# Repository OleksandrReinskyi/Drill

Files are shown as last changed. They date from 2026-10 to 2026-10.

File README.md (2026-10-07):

# Mini wiertarka

## 1. Opis zasady działania
> Autorzy: Oleksandr Reinskyi 262564, Bohdan Pospolita 262562

**Cel:** Podczas domowej produkcji płytek powstała potrzeba wiercenia otworów w tekstolicie. Dlatego powstał pomysł zaprojektowania wiertarki wlaśnie do tych potrzeb. 

System składa się z trzech modułów:
1. **Zasilacza:** Zasilacz od laptopa 20V/4.5A
2. **Płytka modulacji szerokości impulsów:** Uklad służący do regulowania napięcia na silniku.
3. **Silnik:** Szczotkowy silnik RS385-17V

---

### Zasada działania płytki:

1. Pierwszy wzmacniacz w układzie scalonym LM358 pełni rolę komparatora z histerezą (zrealizowaną za pomocą dzielnika napięcia oraz rezystora w pętli dodatniego sprzężenia zwrotnego), generując napięcie piłokształtne na kondensatorze.

2. Drugi wzmacniacz w układzie LM358 działa jako komparator, porównując napięcie na kondensatorze z napięciem zadanym na potencjometrze. Na wyjściu powstaje przebieg prostokątny o regulowanej szerokości impulsów, który steruje tranzystorem MOSFET załączającym i wyłączającym silnik. Tranzystor jest chroniony przed przepięciami za pomocą szybkiej diody impulsowej.

---

## 2. Realizacja

### Wyniki symulacji (KiCAD)

1. **Przebieg napięcia na bramce tranzystora, gdy wartości rezystorów potencjometra były następujące: 3k/7k (górny/dolny):**

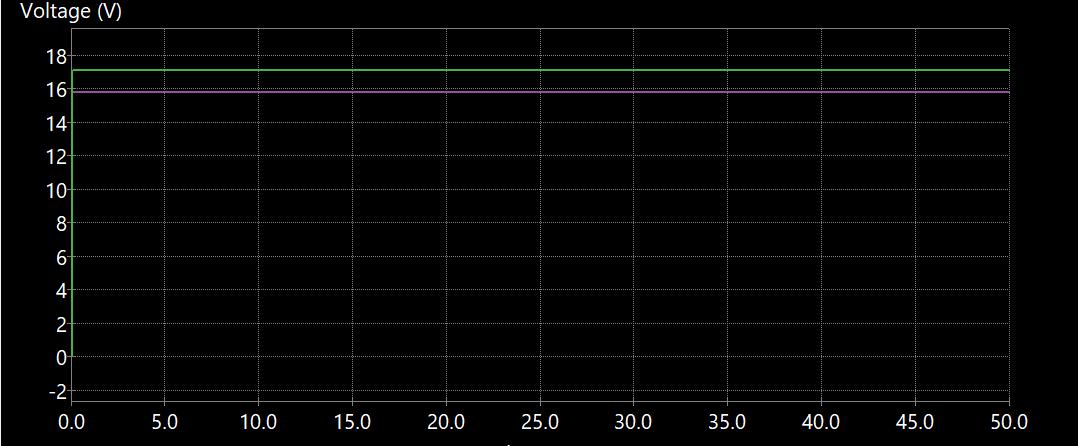
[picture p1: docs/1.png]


2. **Przebieg napięcia na bramce tranzystora, gdy wartości rezystorów potencjometra były następujące: 3k/7k (górny/dolny):**

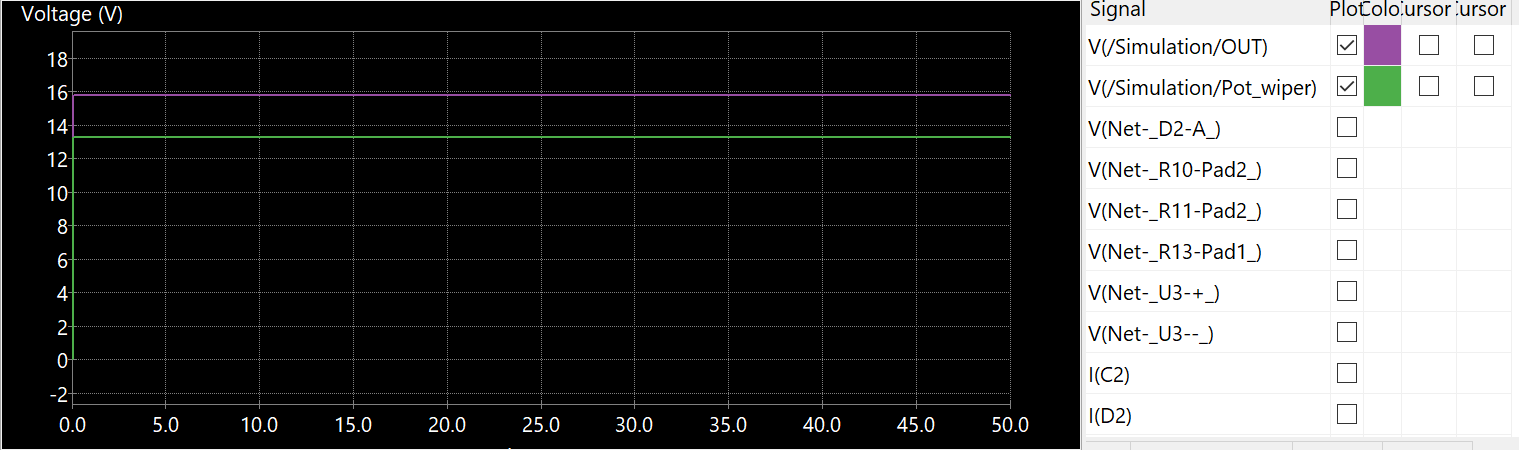
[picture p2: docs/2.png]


### Obudowa
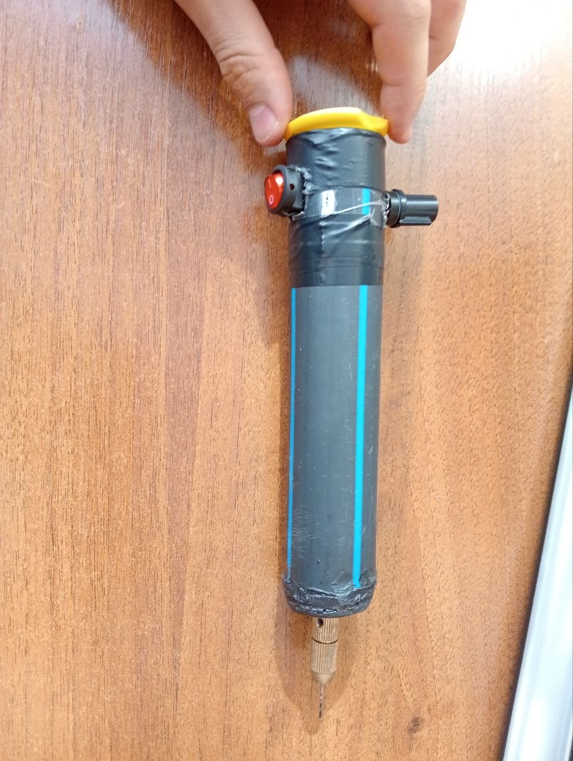
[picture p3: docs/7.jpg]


### Demonstracja wideo
[Link](https://www.youtube.com/shorts/_mu2Nx89iDE)

### Zmontowany prototyp
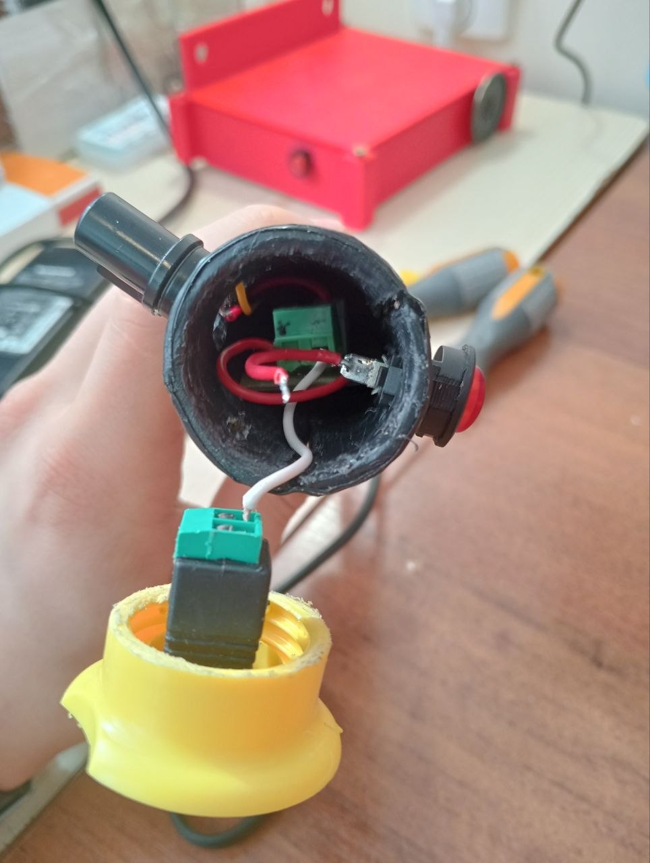
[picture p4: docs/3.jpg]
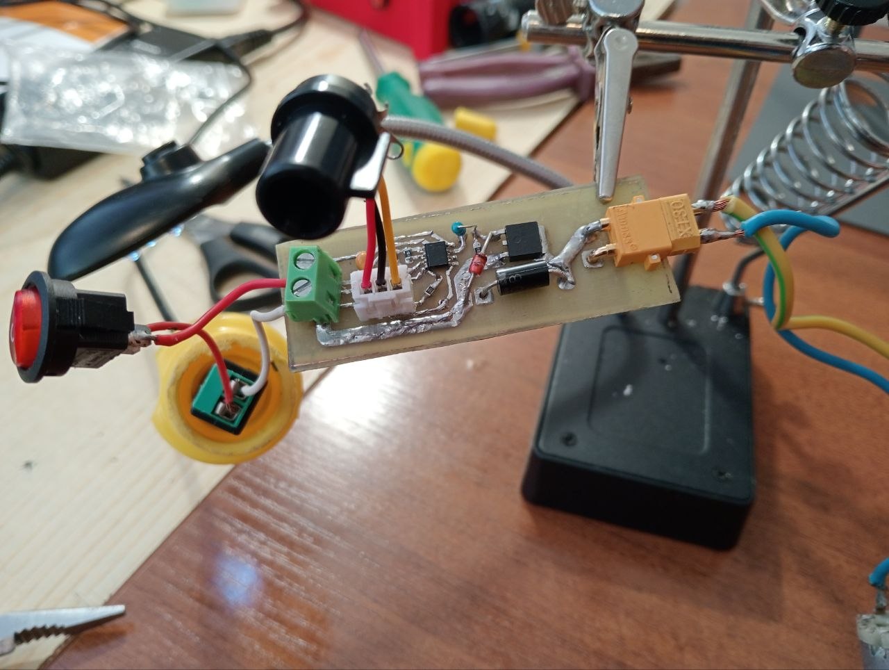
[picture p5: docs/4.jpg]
|  |  |
|--|--|
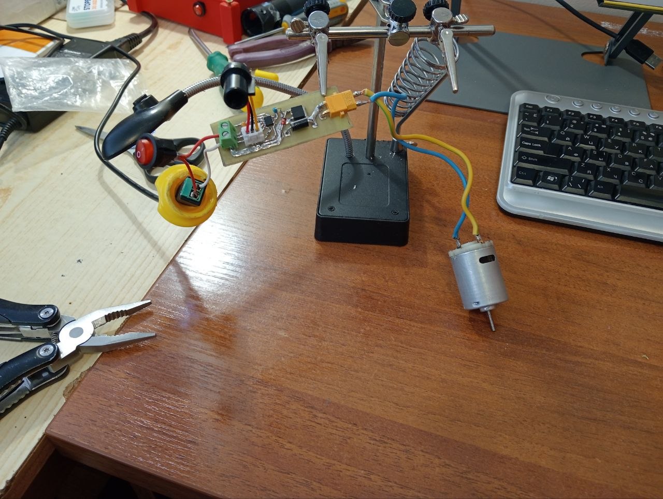
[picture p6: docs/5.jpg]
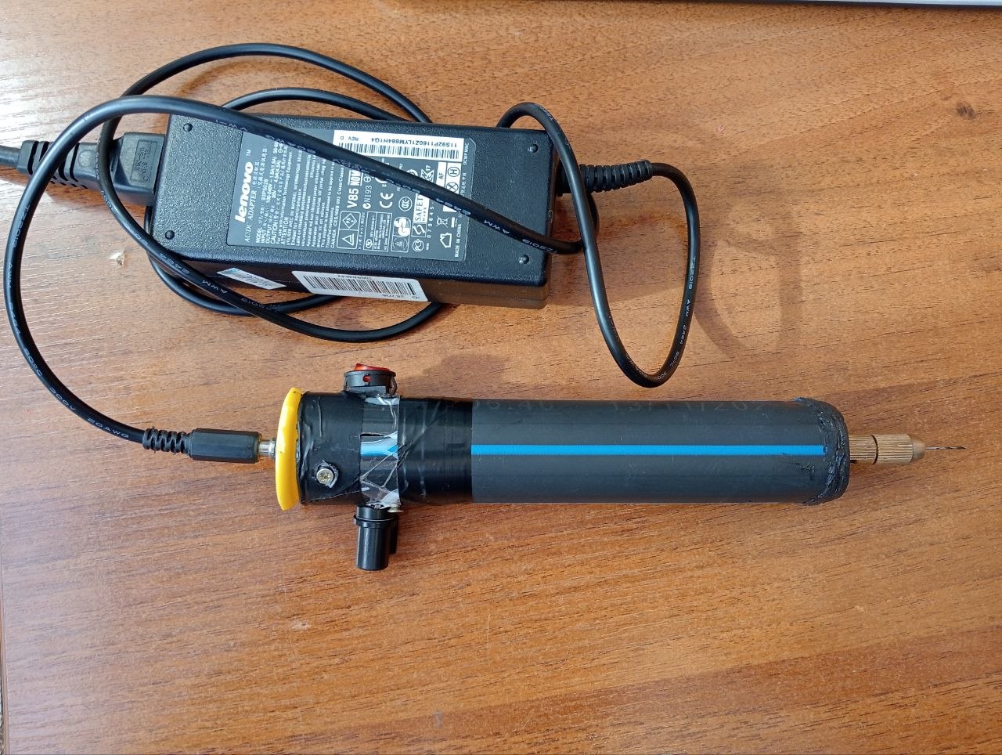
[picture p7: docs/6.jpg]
|  |  |

## 3. Problemy i napotkane trudności 

### Zidentyfikowane problemy:
* Zły dobór wartości rezystorów dzielnika napięcia oraz rezytora sprężenia zwrotnego spowodował, że w sterowaniu napięciem bierze udział nie cała ścieżka potencjometra, a tylko część. Rozwiązać ten problem można dobierając te wartości tak, żeby kondesator ładował się do ~20V oraz rozładowywał się do ~0V.

### Napotkane trudności:
#### 1. Symulacja 
* Najpierw podłączyliśmy wejście drugiego wzmaczniacza do wyjście pierwszego, a nie do węzła kondesatora, i dlatego regulacja była niemożliwa.

#### 2. Dóbór wartości
* Najpierw chcieliśmy zastosować zasiłacz o wartości napięcia 12V, ale wartość maksymalnego prądu silnika (stall current = 5A) przekraczała możliwości zasiłacza. Dlatego wybraliśmy zasiłacz na 20V. Nie zauważyliśmy, że dla wybranego tranzystora LR3103 wartość napięcia między Gate a Source może wynosić maksymalnie 16v. Dlatego musieliśmy dolutować diodę Zenera, która stabilizuje napięcie na poziomie 10v.  

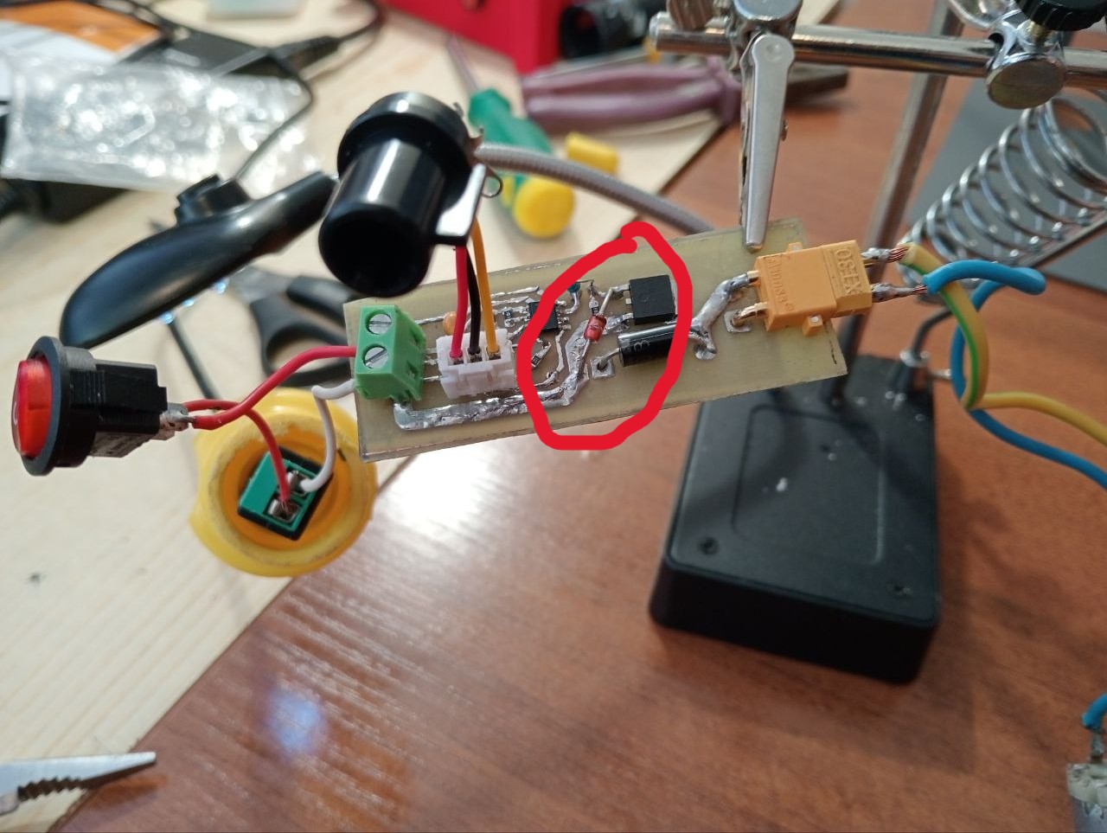
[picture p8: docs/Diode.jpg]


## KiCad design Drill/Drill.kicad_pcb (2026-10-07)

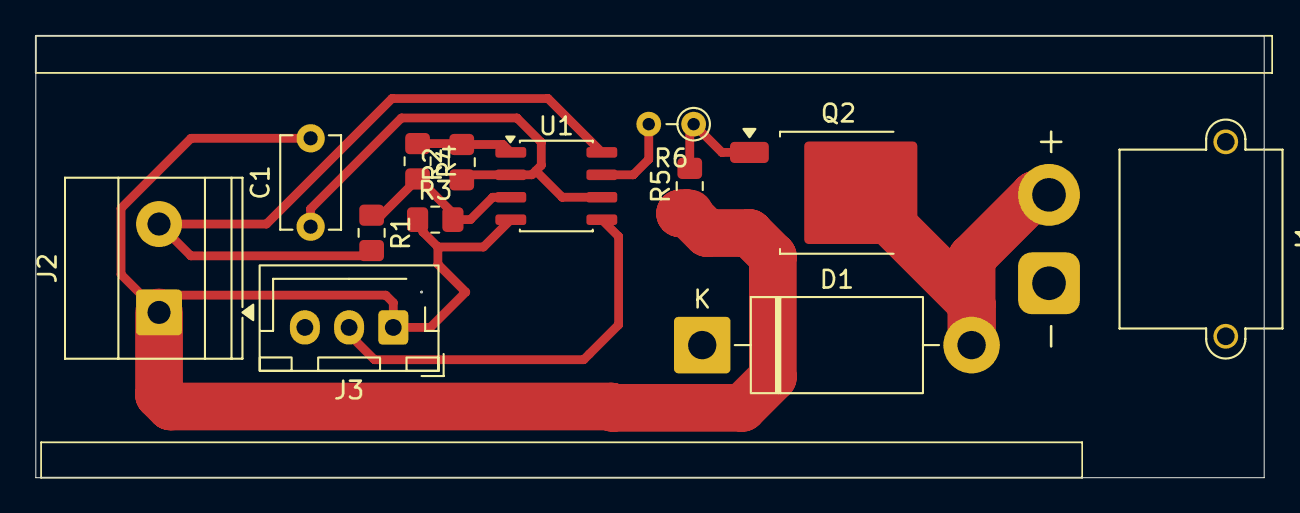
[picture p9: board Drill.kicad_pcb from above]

Board: 2 copper layers, 69.5 x 25.0 mm, 13 parts (0 on the bottom side), 9 nets.

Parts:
C1: 1u; C_Disc_D5.1mm_W3.2mm_P5.00mm
D1: UF5408; D_DO-201AD_P15.24mm_Horizontal
J1: Conn_01x02_Socket; AMASS_XT30PW-M_1x02_P2.50mm_Horizontal
J2: Screw_Terminal_01x02; TerminalBlock_Phoenix_MKDS-1,5-2_1x02_P5.00mm_Horizontal
J3: Conn_01x03_Socket; JST_XH_B3B-XH-AM_1x03_P2.50mm_Vertical
Q2: lr3103; TO-252-2
R1, R2, R3, R5: 1k; R_0805_2012Metric_Pad1.20x1.40mm_HandSolder
R4: 10k; R_0805_2012Metric_Pad1.20x1.40mm_HandSolder
R6: 100; R_Axial_DIN0204_L3.6mm_D1.6mm_P2.54mm_Vertical
U1: LM358; SO-8_3.9x4.9mm_P1.27mm

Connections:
+12V: D1.1 (K), J1.1, J2.2, J3.3, R1.2, U1.8 (V+)
GND: C1.2, J2.1, J3.1, Q2.3 (S), R3.1, R5.1, U1.4 (V-)
unnamed: D1.2 (A), J1.2, Q2.2 (D)
unnamed: J3.2, U1.5 (+)
unnamed: Q2.1 (G), R5.2, R6.1
unnamed: R2.2, R4.1, U1.1
unnamed: R6.2, U1.7
unnamed: R1.1, R3.2, R4.2, U1.3 (+)
unnamed: C1.1, R2.1, U1.2 (-), U1.6 (-)
